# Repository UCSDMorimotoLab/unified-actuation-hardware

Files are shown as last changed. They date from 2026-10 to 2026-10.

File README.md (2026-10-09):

<h1 align="center">A Unified Continuum Robot Actuation Platform - Hardware</h1>

<p align="center">
  Open-source hardware to help researchers get started with high-DOF robots.<br>
  We focus on continuum robots, but the platform is agnostic to robot type!
</p>

<p align="center">
  <a href="https://ucsdmorimotolab.github.io/unified-actuation/"><b>Project website</b></a>
  &nbsp;·&nbsp;
  <a href="https://drive.google.com/file/d/1_eJ_vQgiMd1IlGs77tz4AiUZTHAcJVn4/view"><b>Full actuation assembly video</b></a>
  &nbsp;·&nbsp;
  <a href="https://github.com/UCSDMorimotoLab/unified-actuation-software"><b>Looking for software?</b></a>
</p>

---

## What's in this repo

| | |
|---|---|
| [Assembly guide](AssemblyDoc_6-24-2026.pdf) | Step-by-step mechanical assembly instructions (PDF) |
| [Bill of materials](BOM_6-25-2026.xlsx) | Parts list for the actuation system (Excel) |
| [CAD and print files](CAD_and_print_files/) | SolidWorks assemblies and 3D-print files |

The [full actuation assembly video](https://drive.google.com/file/d/1_eJ_vQgiMd1IlGs77tz4AiUZTHAcJVn4/view) walks through the complete build alongside the assembly guide.

## System overview

<p align="center">
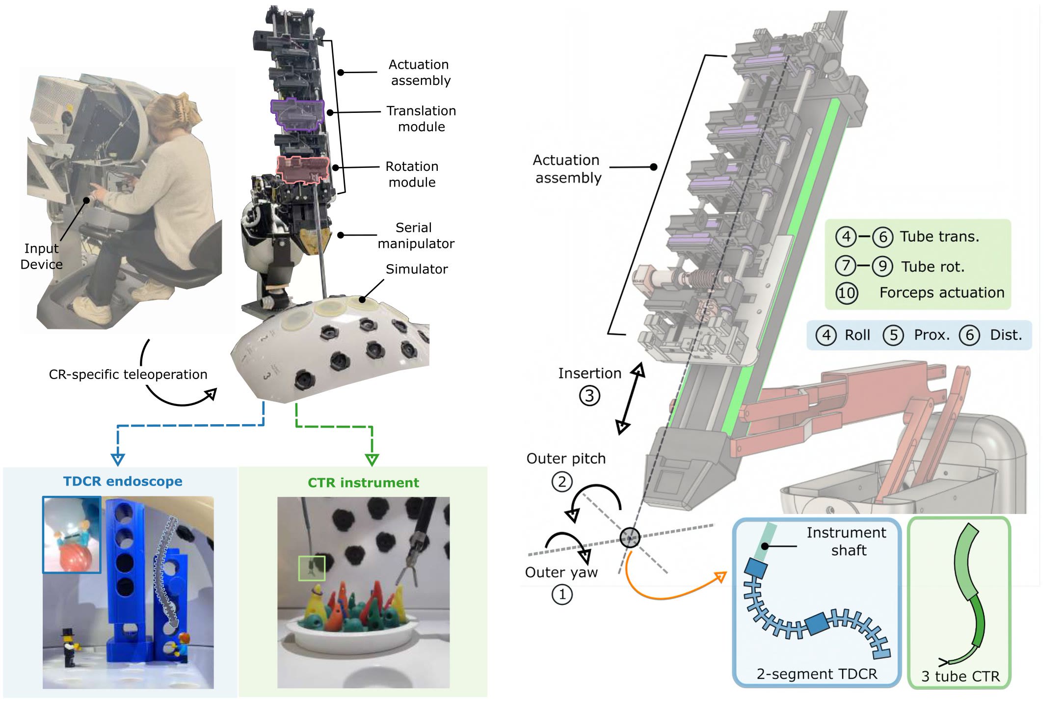
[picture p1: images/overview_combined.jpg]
Left: system overview, an operator at the input device teleoperates the actuation assembly on a serial manipulator over a surgical simulator, driving a TDCR endoscope and a CTR instrument. Right: degrees of freedom, outer yaw, outer pitch and insertion plus actuation-assembly DOFs for a 2-segment T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
  
</p>

## Design overview

<p align="center">
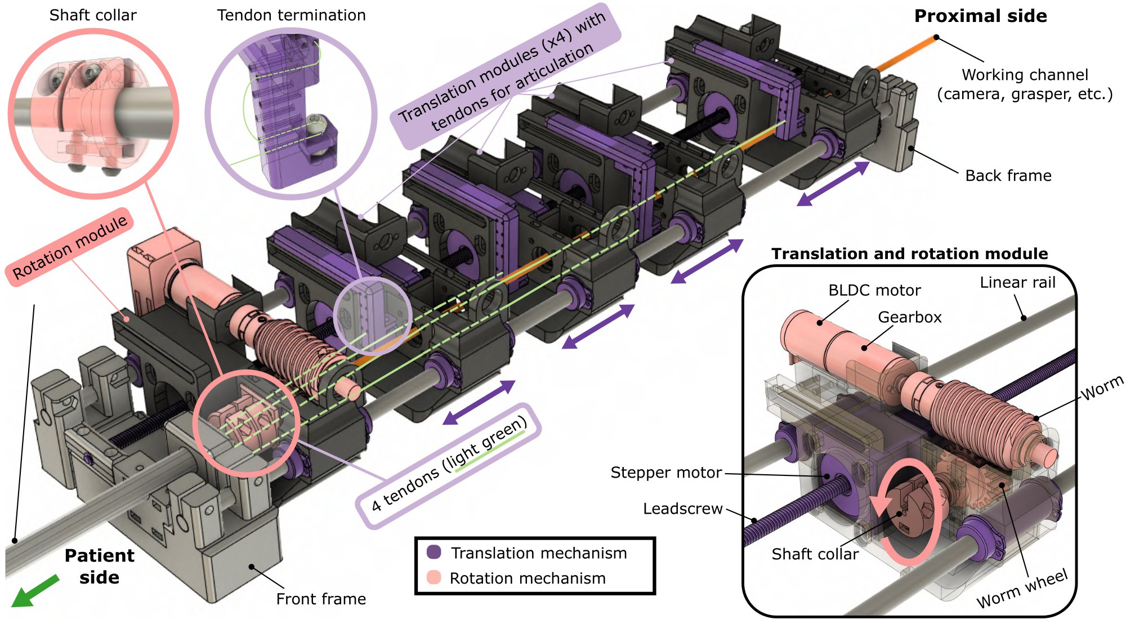
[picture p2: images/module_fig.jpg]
Annotated CAD render of the actuation assembly: a rotation module and four translation modules on linear rails, with tendons routed to each module and a central working channel
  
</p>

<p align="center">
  <em>An example actuation assembly for a TDCR. Modules can be reconfigured to match the robot's design and number of DOFs. A central working channel accommodates cameras, forceps, and other tools.</em>
</p>

## License

The CAD files, print files, and documentation in this repository are released under the [MIT License](LICENSE).

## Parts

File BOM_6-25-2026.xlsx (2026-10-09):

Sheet: Actuation Components for TDCR C
NOTE: "Actuation Components" refers exclusively to the backend motorized drive hardware and explicitly exclude continuum robot assemblies.
 | Price of Actuation Components for Tendon-driven CR (TDCR): | $1095.00 | Price of TDCR: | $110.20
 | Part Name | Vendor | Part No. & Link | Quantity | Price Per Unit | Item Total | Notes
Actuation Components for Tendon-driven Continuum Robot (TDCR) Config (Excludes CR) |  |  |  |  |  |  | - 1 roll module - 4 tendon modules
Off-the-shelf Components | Linear Actuator (Stepper Motor) | Nanotec | LA281S10-A-THCA (https://www.nanotec.com/us/en/products/2405-la281s10-a-thca) | 4 | $113.30 | $453.20
 | Brushless Direct Current (BLDC) Motor | Maxon | 283828 (https://www.maxongroup.us/maxon/view/product/283828) | 1 | $190.88 | $190.88 | - Price at time bought, price as of Jan 30th, 2026 is $206.15 per unit when buying 5 or more
 | BLDC Motor Planetary Gearhead | Maxon | 110322 (https://www.maxongroup.us/maxon/view/product/gear/planetary/gp16/110322) | 1 | $63.13 | $63.13 | - Price at time bought, price as of Jan 30th, 2026 is $68.18 per unit when buying 5 or more
 | Worm Wheel Bearing (Hollow Shaft) | McMaster-Carr | 57155K303 (https://www.mcmaster.com/57155K303/) | 1 | $6.67 | $6.67
 | Worm | McMaster-Carr | 57545K634 (https://www.mcmaster.com/57545K634/) | 1 | $15.63 | $15.63
 | Hollow Shaft (Worm Wheel) | McMaster-Carr | 89495K565-89495K568 (https://www.mcmaster.com/89495K565-89495K568/) | 1 | $17.40 | $17.40 | - For length of 4 ft, buy only once for 2 systems
 | Solid Shaft (Worm Shaft) | McMaster-Carr | 4634T32-4634T323 (https://www.mcmaster.com/4634T32-4634T323/) | 1 | $3.04 | $3.04 | - For length of 3 ft, buy only once for 2 systems
 | Motor (3 mm) Shaft Coupling | McMaster-Carr | 59985K1-59985K101 (https://www.mcmaster.com/59985K1-59985K101/) | 1 | $19.62 | $19.62
 | Worm (6 mm) Shaft Coupling | McMaster-Carr | 59985K1-59985K104 (https://www.mcmaster.com/59985K1-59985K104/) | 1 | $19.62 | $19.62
 | Open Housing Bearing (Worm) | McMaster-Carr | 57155K472 (https://www.mcmaster.com/57155K472/) | 1 | $10.00 | $10.00
 | Linear Bearing | Misumi | LMUW6 (https://us.misumi-ec.com/vona2/detail/110300026540/?HissuCode=LMUW6) | 10 | $16.58 | $165.80 | - Price when buying more than 10 or more
 | Retaining/Snap Ring | McMaster-Carr | 9968K52 (https://www.mcmaster.com/9968K52/) | 1 | $10.86 | $10.86 | - Sold in Packs of 50, buy only once for both systems
 | Limit Switch | Iridescent (Amazon) | KW11-3Z-2 (https://www.amazon.com/MXRS-5-5cm-Momentary-Button-Switch/dp/B07MW2RPJY?pid=ujgRott&s=industrial) | 1 | $5.29 | $5.29 | - Sold in Packs of 12, buy only once for both systems
 |  |  |  |  |  | 0
 | Linear Motion Shaft | McMaster-Carr | 6112K42 (https://www.mcmaster.com/6112k42/) | 2 | $12.98 | $25.96 | -
 | Lead Screw | Nanotec | SCREW-AAA-THCA-1000 (https://www.nanotec.com/us/en/products/10762-screw-aaa-thca-1000) | 1 | $87.90 | $87.90 | - For length of 1 m, buy only once for 2 systems
Custom Components | Module Frame | Formlabs (Tough 1500 V2) | Module_Frame_012 | 5
 | Worm Wheel | Formlabs (Tough 1500 V2) | Worm_Wheel_003 | 1
 | BLDC Clamp | Bambu Lab (PLA) | BLDC_Constraint | 1
 | Shaft Coupling Disc | Bambu Lab (PLA) | Shaft_Coupling_Disc | 1
 | Worm-Bearing Spacer | Bambu Lab (PLA) | Worm_Spacer_006 | 1
 | Backlash Panel | Bambu Lab (PLA) | Backlash_Panel_003 | 1
 | Shaft Collar - TDCR | Formlabs (Tough 1500 V2) | TDCR_Shaft_Collar | 1
 | Wire Router | Bambu Lab (PLA) | Wire_Router_002 | 5
 | Front Frame | Bambu Lab (PLA) | Front_Frame_008 | 1
 | Back Frame | Bambu Lab (PLA) | Back_Frame_003 | 1
 | Lead Screw Holder Bottom | Bambu Lab (PLA) | Lead_Screw_Holder_Bottom_003 | 2
 | Lead Screw Holder Top | Bambu Lab (PLA) | Lead_Screw_Holder_Top_003 | 2
 | Tendon L Joint | Formlabs (Tough 1500 V2) | LJoint_Tendon_Top_Termination_008 | 4
 | Roll Module Stationary Spacer | Bambu Lab (PLA) | Roll_Module_Stationary_Spacer | 2
 | Internal Tendon Tube Spacer | Formlabs (Tough 1500 V2) | Internal_Tendon_Tube_Spacer_002 | 1
 | TDCR Shaft Holder | Bambu Lab (PLA) | TDCR_Shaft_Holder | 1
 | TDCR Shaft Clamp | Bambu Lab (PLA) | TDCR_Shaft_Clamp | 1 |  |  | - only required to constrain rotation

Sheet: Actuation Components for CTR Co
NOTE: "Actuation Components" refers exclusively to the backend motorized drive hardware and explicitly exclude continuum robot assemblies.
 | Price of Actuation Components for Concentric Tube Robots (CTR): | $1918.08 | Price of CTR: | $651.47
 | Part Name | Vendor | Part No. & Link | Quantity | Price Per Unit | Item Total | Notes
Actuation Components for Concentric Tube Robot (CTR) Config (Excludes CR) |  |  |  |  |  |  | - 3 CTR modules - Instrument module
Off-the-shelf Components | Linear Actuator (Stepper Motor) | Nanotec | LA281S10-A-THCA (https://www.nanotec.com/us/en/products/2405-la281s10-a-thca) | 3 | $113.30 | $339.90
 | Brushless Direct Current (BLDC) Motor | Maxon | 283828 (https://www.maxongroup.us/maxon/view/product/283828) | 4 | $190.88 | $763.52 | - Price at time bought, price as of Jan 30th, 2026 is $206.15 per unit when buying 5 or more
 | BLDC Motor Planetary Gearhead | Maxon | 110322 (https://www.maxongroup.us/maxon/view/product/gear/planetary/gp16/110322) | 4 | $63.13 | $252.52 | - Price at time bought, price as of Jan 30th, 2026 is $68.18 per unit when buying 5 or more
 | Worm Wheel Bearing (Hollow Shaft) | McMaster-Carr | 57155K303 (https://www.mcmaster.com/57155K303/) | 6 | $6.67 | $40.02
 | Worm | McMaster-Carr | 57545K634 (https://www.mcmaster.com/57545K634/) | 3 | $15.63 | $46.89
 | Hollow Shaft (Worm Wheel) | McMaster-Carr | 89495K565-89495K568 (https://www.mcmaster.com/89495K565-89495K568/) | 1 | $17.40 | $17.40 | - For length of 4 ft, buy only once for 2 systems
 | Solid Shaft (Worm Shaft) | McMaster-Carr | 4634T32-4634T323 (https://www.mcmaster.com/4634T32-4634T323/) | 1 | $3.04 | $3.04 | - For length of 3 ft, buy only once for 2 systems
 | Motor (3 mm) Shaft Coupling | McMaster-Carr | 59985K1-59985K101 (https://www.mcmaster.com/59985K1-59985K101/) | 4 | $19.62 | $78.48
 | Worm (6 mm) Shaft Coupling | McMaster-Carr | 59985K1-59985K104 (https://www.mcmaster.com/59985K1-59985K104/) | 4 | $19.62 | $78.48
 | Open Housing Bearing (Worm) | McMaster-Carr | 57155K472 (https://www.mcmaster.com/57155K472/) | 3 | $10.00 | $30.00
 | Linear Bearing | Misumi | LMUW6 (https://us.misumi-ec.com/vona2/detail/110300026540/?HissuCode=LMUW6) | 6 | $16.58 | $99.48 | - Price when buying more than 10 or more
 | Retaining/Snap Ring | McMaster-Carr | 9968K52 (https://www.mcmaster.com/9968K52/) | 1 | $10.86 | $10.86 | - Sold in Packs of 50, buy only once for both systems
 | Limit Switch | Iridescent (Amazon) | KW11-3Z-2 (https://www.amazon.com/MXRS-5-5cm-Momentary-Button-Switch/dp/B07MW2RPJY?pid=ujgRott&s=industrial) | 1 | $5.29 | $5.29 | - Sold in Packs of 12, buy only once for both systems
 |  |  |  |  |  | 0
 | Linear Motion Shaft | McMaster-Carr | 6112K42 (https://www.mcmaster.com/6112k42/) | 2 | $12.98 | $25.96
 | Lead Screw | Nanotec | SCREW-AAA-THCA-1000 (https://www.nanotec.com/us/en/products/10762-screw-aaa-thca-1000) | 1 | $87.90 | $87.90 | - For length of 1 m, buy only once for 2 systems
 |  |  |  |  |  | 0
 | ACME Lead Screw | McMaster-Carr | 99030A981 (https://www.mcmaster.com/99030A981/) | 1 | $23.34 | $23.34
 | ACME Hex Nut | McMaster-Carr | 94815A007 (https://www.mcmaster.com/94815A007/) | 1 | $3.51 | $3.51
 | Compression Spring (23/64 x 1-3/8 in) | Performance Tool (O'Reilly Auto Parts) | W5200 (https://www.oreillyauto.com/detail/c/performance-tool/performance-tool-200-piece-spring-assortment/pfm0/w5200) | 1 | $11.49 | $11.49 | - 200 part spring assortment but only need 1 unit of 1 specific spring
Custom Components | Module Frame | Formlabs (Tough 1500 V2) | Module_Frame_012 | 3
 | Worm Wheel | Formlabs (Tough 1500 V2) | Worm_Wheel_003 | 3
 | BLDC Clamp | Bambu Lab (PLA) | BLDC_Constraint | 3
 | Coupling Disc | Bambu Lab (PLA) | Shaft_Coupling_Disc | 4
 | Worm Bearing Spacer | Bambu Lab (PLA) | Worm_Spacer_006 | 3
 | Backlash Panel | Bambu Lab (PLA) | Backlash_Panel_003 | 3
 | Shaft Collar - CTR Tube 1 | Formlabs (Tough 1500 V2) | CTR_Shaft_Collar_Tube1 | 1
 | Shaft Collar - CTR Tube 2 | Formlabs (Tough 1500 V2) | CTR_Shaft_Collar_Tube2 | 1
 | Shaft Collar - CTR Tube 3 | Formlabs (Tough 1500 V2) | CTR_Shaft_Collar_Tube2 | 1
 | Wire Router | Bambu Lab (PLA) | Wire_Router_002 | 5
 | Front Frame | Bambu Lab (PLA) | Front_Frame_008 | 1
 | Back Frame | Bambu Lab (PLA) | Back_Frame_003 | 1
 | Lead Screw Holder Bottom | Bambu Lab (PLA) | Lead_Screw_Holder_Bottom_003 | 2
 | Lead Screw Holder Top | Bambu Lab (PLA) | Lead_Screw_Holder_Top_003 | 2
 | CTR Tube Holder | Bambu Lab (PLA) | CTR_Tube_Holder
 | Instrument Module Frame | Bambu Lab (PLA) | Instrument_ModuleM6_Frame_002 | 1
 | Instrument Tendon Constraint Module | Bambu Lab (PLA) | Instrument_Tendon_Termination_Module_004 | 1
 | Instrument Spacer | Bambu Lab (PLA) | Instrument_Spacer

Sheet: Electronic Components
 | Price of Electronic Components for 2 Complete Systems: | $3530.288
 | Part Name | Vendor | Part No. & Link | Quantity | Price Per Unit | Item Total | Notes
Electronic Components |  |  |  |  |  |  | - supports 2 actuation systems, 1 CTR and 1 TDCR
Off-the-shelf Components | Nanotec Motor Controller Boards | Nanotec | CM-CPB3-44-0005-1 (https://www.nanotec.com/us/en/products/10303-cm-cpb3-44-0005-1) | 3 | $933 | $2799
 | 60V, 15A, 300W Power Supply | Multicomp Pro (Newark) | MP710257 US (https://www.newark.com/multicomp-pro/mp710257-us/dc-power-supply-prog-15a-60v-300w/dp/42AH2837) | 1 | $324 | $324
 | TP-Link 5 Port Ethernet Switch | TP-Link (Amazon) | TL-SG105 (https://www.amazon.com/gp/product/B00A128S24/ref=ox_sc_act_title_8?smid=ATVPDKIKX0DER&th=1) | 1 | $17.99 | $17.99
 | 22 Gauge 8 Conductor Electrical Wire | LEDLampsWorld (Amazon) | B0CLZDX27V (https://www.amazon.com/gp/product/B0CLZDX27V/ref=ox_sc_act_title_7?th=1) | 2 | $44.99 | $89.98 | - 100 ft per order
 | 22 Gauge 4 Conductor Electrical Wire | Enerjour (Amazon) | 22-4C-100FT-CA-ZW (https://www.amazon.com/Conductor-Electrical-Stranded-Extension-Automotive/dp/B0CV7WLG29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) | 2 | $33.98 | $33.98 | - 100 ft per order
 | Molex Mini-Fit 8 Circuit | DigiKey | 23-0766500077-ND (https://www.digikey.com/en/products/detail/molex/0766500077/2115941) | 17 | $0.94 | $16.05 | - connectors for BLDC motors to Nanotec boards
 | Molex Mini-Fit 4 Circuit | DigiKey | 23-0766500075-ND (https://www.digikey.com/en/products/detail/molex/0766500075/2115923) | 22 | $0.84 | $18.48 | - connectors for stepper motors to Nanotec boards
 | Molex Mini-Fit 2 Circuit | DigiKey | 23-0766500074-ND (https://www.digikey.com/en/products/detail/molex/0766500074/2115924) | 10 | $0.60 | $6.00 | - connectors for limit switches to Nanotec boards
 | 8 pin jumper Female 2.54 pitch | DigiKey | 1528-4939-ND (https://www.digikey.com/en/products/detail/adafruit-industries-llc/4939/14552336) | 6 | $0.95 | $5.70
 | 2x12 Position Terminal Block Dist. Module | Oono Electronics (Amazon) | ‎D-1410 (https://www.amazon.com/gp/product/B08TBXQ7H6/ref=ox_sc_act_title_3?smid=A2OVMUS055KMW5&th=1) | 1 | $10.99 | $10.99
 | M3 6+6mm F/M Brass Hex Standoff | uxcell (Amazon) | ‎a18091400ux0125 (https://www.amazon.com/gp/product/B07KWVD986/ref=ox_sc_act_title_2?smid=A30WUG2ZDGM0XM&psc=1) | 1 | $9.59 | $9.59
 | Ethernet Cable - Cat 6 | Cable Matters (Amazon) | 160001-BLK-1x5 (https://www.amazon.com/Cable-Matters-5-Pack-Snagless-Ethernet/dp/B00C4U030G) | 1 | $9.99 | $9.99 | - 1 ft length
 | 22 AWG wire | SZNNZD (Amazon) | DGHY-GJX-BOX1 (https://www.amazon.com/dp/B09Y9B4PVN?ref=ppx_yo2ov_dt_b_product_details&th=1) | 2 | $14.99 | $29.98 | - Wiring for individual motor connections
 | 16 AWG wire | Haerkn (Amazon) | ‎B0746HRVZP (https://www.amazon.com/Electrical-Gauge-Silicone-Cable-Black/dp/B0746HRVZP) | 1 | $8.88 | $8.88 | - Wiring for power to each board
 | 3 Fan Kit | Darkrock (Amazon) | B0CD7P3S8Q (https://www.amazon.com/DARKROCK-Computer-Performance-Hydraulic-Warranty/dp/B0CD7P3S8Q) | 1 | $8.99 | $8.99
 | Ethernet Female to Male | Gintooyun (Amazon) | ‎738632035182 (https://www.amazon.com/gp/product/B08D3BQZ77/ref=ox_sc_act_title_2?smid=A1L0CC1FACMFXH&th=1) | 1 | $7.99 | $7.99
 | Velcro Straps | (Amazon) | ‎Ct-ru-50-bk-01 (https://www.amazon.com/50PC-Cable-Ties-Reusable-Multi-Purpose/dp/B0G4CBRPDD) | 1 | $15.99 | $15.99
 | Stepper Connectors | DigiKey | 455-1185-ND (https://www.digikey.com/en/products/detail/jst-sales-america-inc/vhr-4n/608626) | 10 | $0.94 | $9.40
 | Stepper Connector Crimps | DigiKey | 455-1319-1-ND (https://www.digikey.com/en/products/detail/jst-sales-america-inc/SVH-41T-P1-1/26213078) | 100 | $0.06 | $5.87 | - Sold in strips of 100
 | Screw Terminal Block | Recoil (Amazon) | B0B6NZ95CD (https://www.amazon.com/Positive-Negative-Terminal-Distribution-Terminals/dp/B0B6NZ95CD) | 1 | $12.50 | $12.50
 | Male to Female Jumper Row Connector | Dupont (Amazon) | B0CCVHQWFX (https://www.amazon.com/Kidisoii-Dupont-Connector-Pre-Crimped-6P-10CM/dp/B0CCVHQWFX?th=1) | 4 | $11.09 | $44.36
 | Controller Connectors - Logic | DigiKey | 455-1902-ND (https://www.digikey.com/en/products/detail/jst-sales-america-inc/XHP-8/923773) | 25 | $0.08 | $2.10
 | Controller Crimps - Logic | DigiKey | 455-1135-100-ND (https://www.digikey.com/en/products/detail/jst-sales-america-inc/SXH-001T-P0-6/26213115) | 100 | $0.03 | $3.14
 | Controller Connectors - Sensors | DigiKey | 455-2141-ND (https://www.digikey.com/en/products/detail/jst-sales-america-inc/PADP-12V-1-S/1300222) | 25 | $0.21 | $5.14
 | Controller Crimps - Sensors | DigiKey | 455-2147-100-ND (https://www.digikey.com/en/products/detail/jst-sales-america-inc/SPH-001T-P0-5L/27687540) | 100 | $0.04 | $3.94 | - Sold in strips of 100
 | Internal Molex Connectors for Steppers | DigiKey | WM19013-ND (https://www.digikey.com/en/products/detail/molex/0510650600/403570) | 10 | $0.09 | $0.93 | - For extra direct stepper motor wiring
 | Blue Pre-Crimped Wires | DigiKey | 0502128000-12-L4-ND (https://www.digikey.com/en/products/detail/molex/0502128000-12-L4/10131006) | 10 | $0.74 | $7.37 | - For extra direct stepper motor wiring
 | Green Pre-Crimped Wires | DigiKey | 0502128000-12-G4-ND (https://www.digikey.com/en/products/detail/molex/0502128000-12-G4/10131008) | 10 | $0.74 | $7.37 | - For extra direct stepper motor wiring
 | Black Pre-Crimped Wires | DigiKey | 0502128000-12-B4-D-ND (https://www.digikey.com/en/products/detail/molex/0502128000-12-B4-D/10131095) | 10 | $0.72 | $7.22 | - For extra direct stepper motor wiring
 | Red Pre-Crimped Wires | DigiKey | 0502128000-12-R4-D-ND (https://www.digikey.com/en/products/detail/molex/0502128000-12-R4-D/10131100) | 10 | $0.74 | $7.37 | - For extra direct stepper motor wiring
Custom Components | Electronics Housing Back Plate |  | ElectronicsHousing_Back_Plate | 1
 | Electronics Housing Bottom Plate |  | ElectronicsHousing_Bottom_Plate | 1
 | Electronics Housing Front Plate |  | ElectronicsHousing_Front_Plate | 1
 | Electronics Housing Side Plate |  | ElectronicsHousing_Side_Plate | 2
 | Electronics Input/Output Shield |  | ElectronicsHousing_IO_Shield_003 | 1
 | L Bracket |  | ElectronicsHousing_LBracket | 8

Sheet: da Vinci Research Kit (dVRK) At
 | Price of dVRK Attachment Components | $38.18
 | Part Name | Vendor | Part No. & Link | Quantity | Price Per Unit | Item Total | Notes
da Vinci Research Kit (dVRK) Attachment Components |  |  |  |  |  |  | - 1 custom sterile adapter - 1 constant-force spring subassembly - (if CTR) 1 modified subassembly trocar
Off-the-shelf Components | Constant Force Spring (CFS) | McMaster-Carr | 9293K114 (https://www.mcmaster.com/9293K114/) | 1 | $7.70 | $7.70
 | 1/4 in Aluminum Sheet (6" x 6") | ZOFORTY (Amazon) | B0B4DV12NK (https://www.amazon.com/Aluminum-Sheet-Finely-Polished-Deburred/dp/B0B4DV12NK?sp_csd=d2lkZ2V0TmFtZT1zcF9hdGY) | 1 | $18.99 | $18.99
 | Compression Spring (7/32" x 11/16") | Performance Tool (O'Reilly Auto Parts) | W5200 (https://www.oreillyauto.com/detail/c/performance-tool/performance-tool-200-piece-spring-assortment/pfm0/w5200) | 1 | $11.49 | $11.49 | - 200 part spring assortment but only need 2 units of 1 specific spring
Custom Components | Spring to PSM Attachment (Cantilever Support) | Bambu Lab (PLA) | Spring_PSM_Attachment | 1 |  | 0
 | Back Frame Loop Attachment | Bambu Lab (PLA) | Back_Frame_Loop | 1 |  | 0
 | CFS Spool | Bambu Lab (PLA) | SpringSpool_PSM_Insert | 1 |  | 0
 | CFS Spool End Cap | Bambu Lab (PLA) | SpringSpool_EndCap |  |  | 0
 | Front Frame CFS Attachment | Bambu Lab (PLA) | Spring_FrontFrame_Attachment | 1 |  | 0
 | Custom Aluminum Sterile Adapter | CO2 Laser Cutter | dVRK_Attachment_MetalBoard | 1 |  | 0
 | Sterile Adapter Clamp Handle | Bambu Lab (PLA) | Moving_Jaw_dVRKclamp | 1 |  | 0
 | Sterile Adapter Base | Bambu Lab (PLA) | Fixed_Jaw_dVRKclamp | 1 |  | 0
 |  |  |  |  |  | 0
 | Modified Trocar Base | Bambu Lab (PLA) | Trocar_Extension_Base_006 | 1 |  | 0
 | Modified Trocar Cover | Bambu Lab (PLA) | Trocar_TopCover | 1 |  | 0
 | Trocar Clamp | Bambu Lab (PLA) | Trocar_EndClamp | 1 |  | 0

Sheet: General Components
 | Price of General Components | $406.76
 | Part Name | Vendor | Part No. & Link | Quantity | Price Per Unit | Item Total | Notes
General Components |  |  |  |  |  |  | - supports 2 actuation systems, 1 CTR and 1 TDCR
Consumables | Assorted M2 Bolts (Socket Head) | Kindroufly (Amazon) | B0B88RFGY9 (https://www.amazon.com/Kindroufly-Washers-Assortment-Stainless-Machine/dp/B0B88RFGY9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) | 2 | $9.98 | $19.96
 | Assorted M2.5 Bolts (Button Head) | Kindroufly (Amazon) | B0B88KWDJ1 (https://www.amazon.com/Kindroufly-Washers-Assortment-Stainless-Machine/dp/B0B88KWDJ1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) | 1 | $9.99 | $9.99
 | Assorted M4 Bolts (Button Head) | Kindroufly (Amazon) | B0B88JB1MK (https://www.amazon.com/Kindroufly-Washers-Assortment-Stainless-Machine/dp/B0B88JB1MK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) | 1 | $9.98 | $9.98
 | Heat-set Inserts |  |  |  |  | 0
 |  |  |  |  |  | 0
 | Tough 1500 V2 Cartridge | Formlabs | RS-C2-TO15-02 (https://formlabs.com/store/materials/tough-1500-resin/) | 2 | $149 | $298
 | Polylactic Acid (PLA) Basic | Bambu Lab | Link (https://us.store.bambulab.com/products/pla-basic-filament) | 2 | $19.99 | $39.98
Reusable Tools | Retaining/Snap Ring Pliers | Irwin (MSC Industrial Direct) | 74039595 (https://www.mscdirect.com/product/details/74039595) | 1 | $18.67 | $18.67
 | 1.5 mm Hex Key | McMaster-Carr | 7289A11 (https://www.mcmaster.com/7289A11/) | 1 | $0.25 | $0.25
 | Hex Fold-up Keys | Bondhus (Amazon) | 12591 (https://www.amazon.com/Bondhus-12591-GorillaGrip-Fold-up-16-Inch/dp/B0006O4AFQ) | 1 | $9.93 | $9.93

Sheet: Continuum Robotic Components
 | Price of TDCR Driven Components | $110.20 | Price of CTR Driven Components: | $651.47
 | Part Name | Vendor | Part No. & Link | Quantity | Price Per Unit | Item Total | Notes
Continuum Robotic Components
TDCR Components (Example Shown in Paper Provided) | Plastic Tube Shaft | McMaster-Carr | https://www.mcmaster.com/8585K821/ | 1 | $4.20 | $4.20
 | 2.8 mm Camera | DoTheCamera | AMC0115USB-D2.8-1.1 (https://dothecamera.com/product/2-8mm-endoscope-module-usb/) | 1 | $106.00 | $106.00
 | Fishing String Wire |  |  |  |  | $0.00
 |  |  |  |  |  | $0.00
 |  |  |  |  |  | $0.00
 | Tendon-driven Continuum Robot (TDCR) | Formlabs (Tough 1500 V2) | CR_dVRK-wrist_321_SLA |  |  | $0.00
 | Tip-mount for Camera | Formlabs (Tough 1500 V2) | CAD Part Name Hyperlinked to Github |  |  | $0.00
CTR Components (Example Shown in Paper Provided) | Xu NiTi Tube 1 | Meko Metalworks | N/A | 1 | $36.10 | $36.10 | - Based on price quoted from Meko metalworks on January 7, 2025
 | Xu NiTi Tube 2 | Meko Metalworks | N/A | 1 | $36.10 | $36.10 | - Based on price quoted from Meko metalworks on January 7, 2025
 | Xu NiTi Tube 3 | Meko Metalworks | N/A | 1 | $36.10 | $36.10 | - Based on price quoted from Meko metalworks on January 7, 2025
 | Heat Treatment for NiTi Tubes | Meko Metalworks | N/A | 1 | $480.00 | $480.00 | - Based on price quoted from Meko metalworks on January 7, 2025
 | Stainless Steel Tube Extension for Tube 1 | McMaster-Carr | 8987K39-8987K517 (https://www.mcmaster.com/8987K39-8987K517/) | 1 | $20.14 | $20.14 | - For length of 3 ft
 | Stainless Steel Tube Extension for Tube 2 | McMaster-Carr | 5560K29-5560K321 (https://www.mcmaster.com/5560K29-5560K321/) | 1 | $24.40 | $24.40 | - For length of 3 ft
 | Stainless Steel Tube Extension for Tube 3 | McMaster-Carr | 8987K24-8987K512 (https://www.mcmaster.com/8987K24-8987K512/) | 1 | $21.49 | $21.49 | - For length of 3 ft
 | Loctite 820 | Loctite (Amazon) | 620 442-62040 (https://www.amazon.com/Loctite-442-62040-Retaining-Compound-Temperature/dp/B000O05C2W) | 1 | $17.35 | $17.35
 | Pulmonary Biopsy Forceps, Oval Jaws | Olympus (eBay) | Olympus: FB-231D eBay: 186999571718 (https://www.ebay.com/itm/186999571718?itmmeta=01K8SPD7XR985XPF7KG5CMC7GX) | 1 | $15.89 | $15.89 | - This item was modified for the application, the proximal handle was decoupled and the sheath was stripped to expose the internal tendons

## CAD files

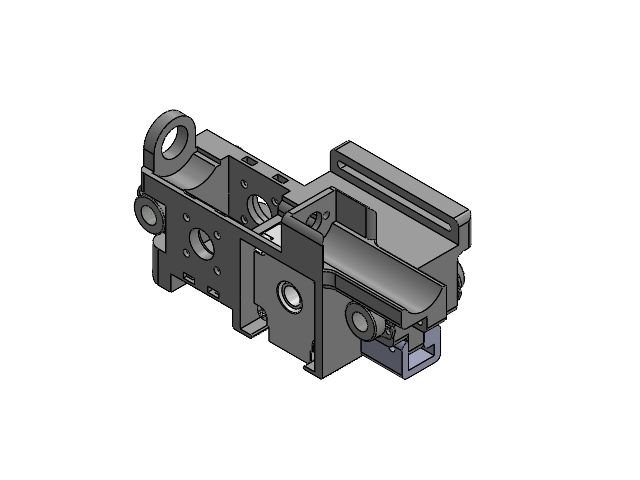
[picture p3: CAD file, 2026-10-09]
CAD_and_print_files/Actuation System Assemblies/Tendon_Module_SubAssem.SLDASM
Module_Frame_012
Stepper_LA281S10-A-THCA
LMUW6 x 2
Wire_Router_002
RetainingRings6mm_9968K52 x 4

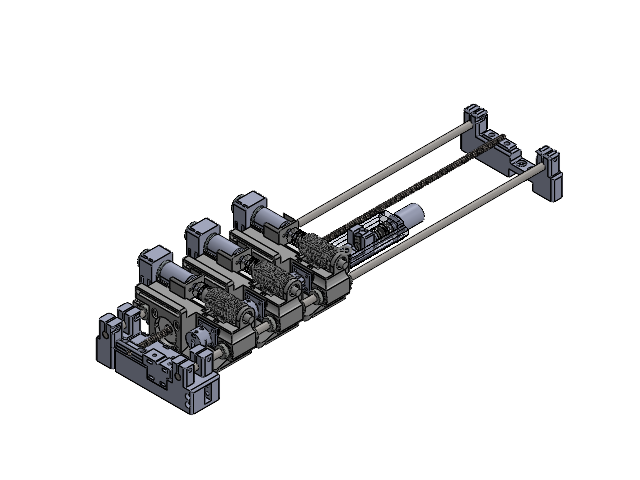
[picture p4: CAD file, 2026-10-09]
CAD_and_print_files/Actuation System Assemblies/CTR_System_Assem006.SLDASM
Back_Frame_003
Front_Frame_008
6112K42_Linear Motion Shaft x 2
Lead_Screw_Holder_Bottom_003 x 2
Lead_Screw_Holder_Top_003
Lead_Screw
Module_Frame_012 x 3
110325_GP16A_0_3NM_5ST_SL.stp x 3
Stepper_LA281S10-A-THCA x 3
MotorShaftCoupling_59985K101 x 4
Shaft_Coupling_Disc x 4
WormShaftCoupling_59985K104 x 4
wormShaft_8920K221 x 3
WormShaftBearing_57155K473 x 3
worm_57545K634 x 3
gearHollowShaft_89955K219 x 3
WormGearShaftBearing_57155K322 x 6
Worm_Wheel_Custom_004 x 3
LMUW6 x 6
BLDCMotor.stp x 3
Wire_Router_002 x 3
Worm_Spacer_006 x 3
Backlash_Panel_003 x 3
BLDC_Constraint x 3
RetainingRings6mm_9968K52 x 12
Instrument_ModuleM6_Frame_002
Instrument_Tendon_Termination_Module_004
98948A111_Acme Hex Nut
95061A601_18-8 Stainless Steel Acme Lead Screw
110324_GP16A_0_25NM_4ST_SL.stp
Instrument_Spacer
CTR_Shaft_Collar_Tube1_002
CTR_Shaft_Collar_Tube2_002
CTR_Shaft_Collar_Tube3_002
CTR_Tube_Holder

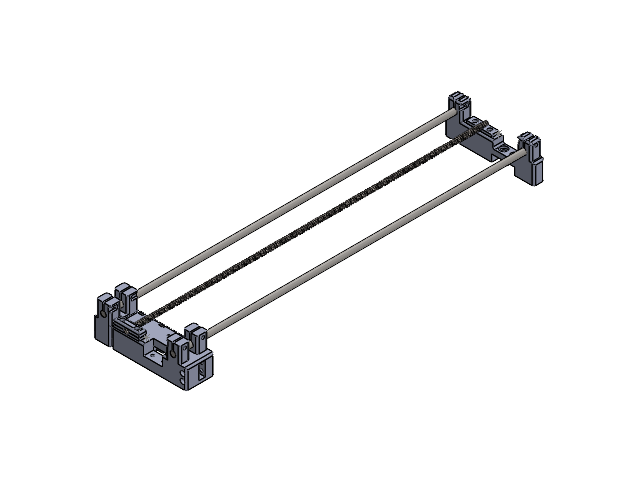
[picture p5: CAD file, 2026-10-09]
CAD_and_print_files/Actuation System Assemblies/Guiderail_SubAssem.SLDASM
Back_Frame_003
Front_Frame_008
6112K42_Linear Motion Shaft x 2
Lead_Screw_Holder_Bottom_003 x 2
Lead_Screw_Holder_Top_003
Lead_Screw

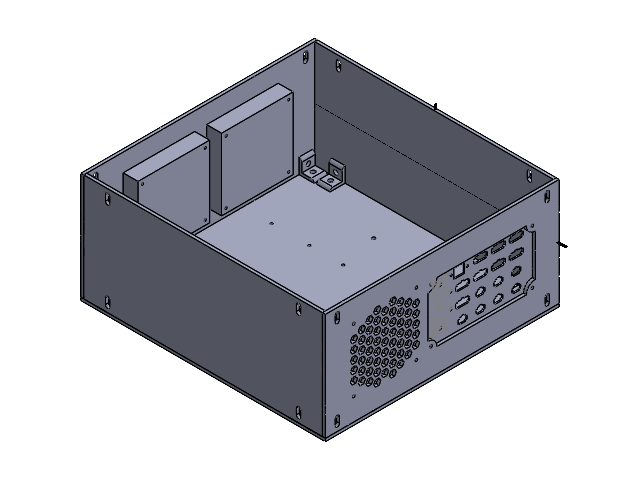
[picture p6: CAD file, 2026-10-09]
CAD_and_print_files/Electronics Housing Box/Electronics_Housing_Box.SLDASM
ElectronicsHousing_Bottom_Plate
ElectronicsHousing_Front_Plate
ElectronicsHousing_Back_Plate
ElectronicsHousing_Side_Plate x 2
ElectronicsHousing_LBracket x 8
Fan x 3
ElectronicsHousing_IO_Shield_003

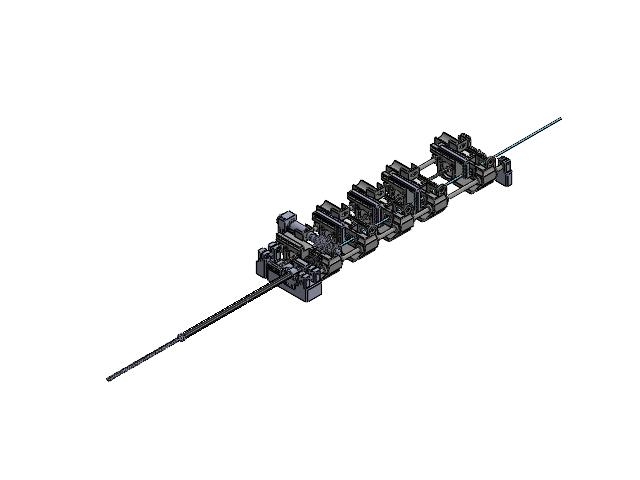
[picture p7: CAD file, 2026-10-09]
CAD_and_print_files/TDCR_in_testingAssem/FinalTDSystemAssem.SLDASM
BackFrameGeneralTestV3
FrontFrameGeneralV3
6112K42_Linear Motion Shaft x 2
LeadScrewHolderBottomV3 x 2
LeadScrewHolderTopV3
LeadScrew
Module_TendonV10 x 5
Stepper_LA281S10-A-THCA x 4
LMUW6 x 10
WireRouterPartV2 x 5
RetainingRings6mm_9968K52 x 20
WorkingChannel
8585K821_Impact-Resistant Polycarbonate Round Tube
InternalTendonSpacerV2 x 2
110325_GP16A_0_3NM_5ST_SL.stp
MotorShaftCoupling_59985K101
FinCouplingDisc_PLA
WormShaftCoupling_59985K104
wormShaft_8920K221
WormShaftBearing_57155K473
worm_57545K634
gearHollowShaft_89955K219
WormGearShaftBearing_57155K322 x 2
wormWheelPrinted_shaftPFV3
BLDCMotor.stp
TendonTubeHolderClamp
BLDCconstraint
OuterRacebacklashpanel_withbackV3
TendonAttachmentSpacer x 2
TDShaftHolder
TDShaftClamp
LJointTendonV8Bottom x 2
LJointTendonV8Top x 2
cDVRK_wrist-321_SLA

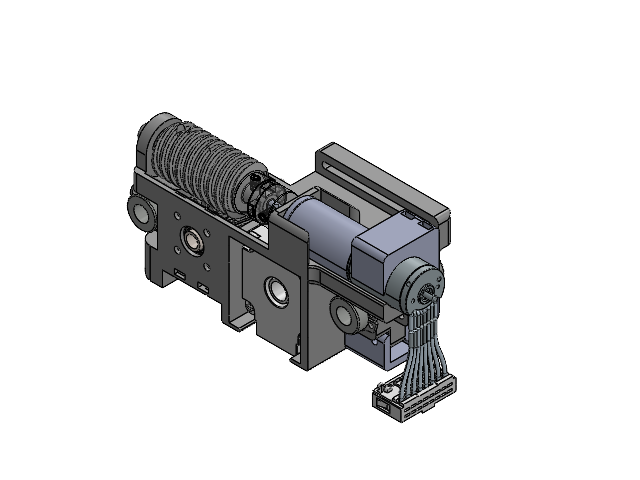
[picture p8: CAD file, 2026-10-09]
CAD_and_print_files/Actuation System Assemblies/CTR_Module_SubAssem.SLDASM
Module_Frame_012
110325_GP16A_0_3NM_5ST_SL.stp
Stepper_LA281S10-A-THCA
MotorShaftCoupling_59985K101
Shaft_Coupling_Disc
WormShaftCoupling_59985K104
wormShaft_8920K221
WormShaftBearing_57155K473
worm_57545K634
gearHollowShaft_89955K219
WormGearShaftBearing_57155K322 x 2
Worm_Wheel_Custom_004
LMUW6 x 2
BLDCMotor.stp
Wire_Router_002
Worm_Spacer_006
Backlash_Panel_003
BLDC_Constraint
RetainingRings6mm_9968K52 x 4

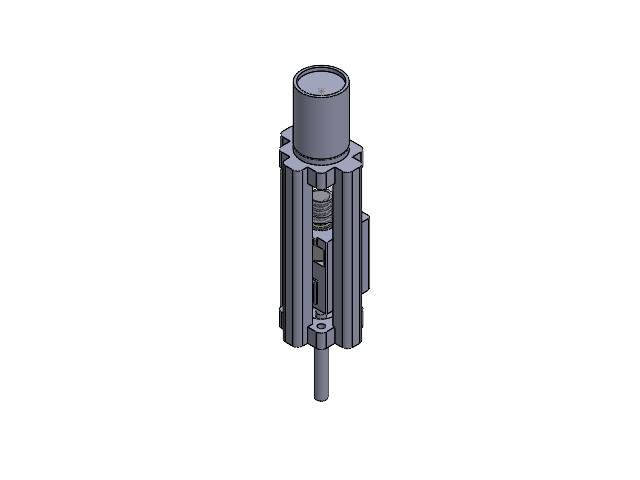
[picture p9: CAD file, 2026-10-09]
CAD_and_print_files/CTR_on_PSM/Instrument Assembly.SLDASM
InstrumentModuleMount
InstrumentWireConstraint_new
98948A111_Acme Hex Nut
95061A601_18-8 Stainless Steel Acme Lead Screw
Shaft Coupler model
110324_GP16A_0_25NM_4ST_SL.stp

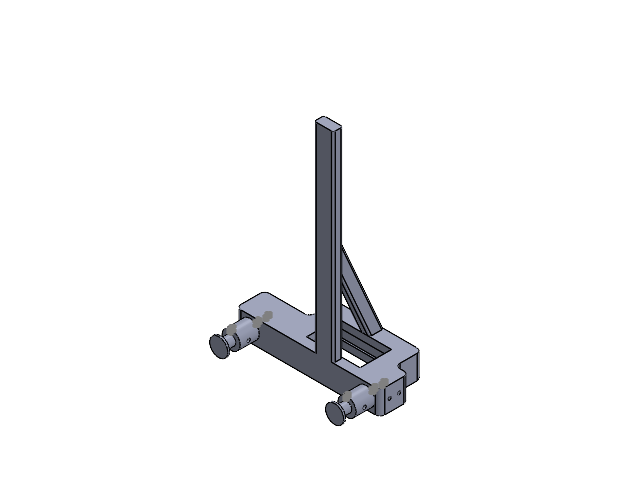
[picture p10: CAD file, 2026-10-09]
CAD_and_print_files/CTR_on_PSM/ConstSpringAttachmentAssem.SLDASM
ConstantForceAttachment
ConstantForceSpool x 2
SpoolEndCap x 2

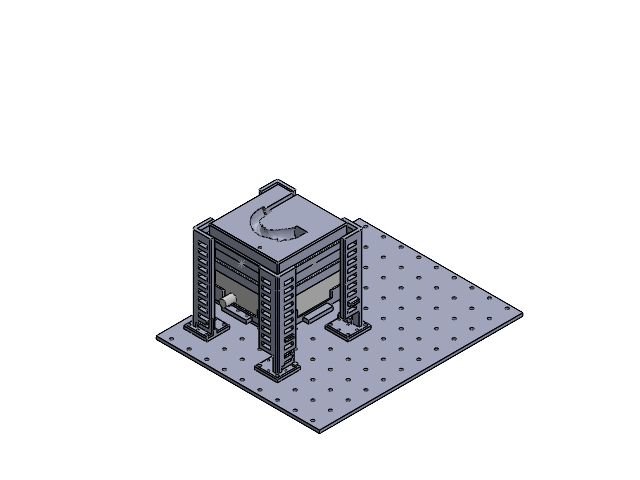
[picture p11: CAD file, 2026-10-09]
CAD_and_print_files/Actuation System Assemblies/Characterization_Testing_Assem.SLDASM
TestingSetup_AcrylicBoard
EM_generator_holder001
MockEM_generator
EMgenerator_Holder_002 x 4
EMgeneratorHolder_SlotPiece x 2
SW_model_D13_neg-003
EM_generator_height_adapter-002
Holder_Pegs

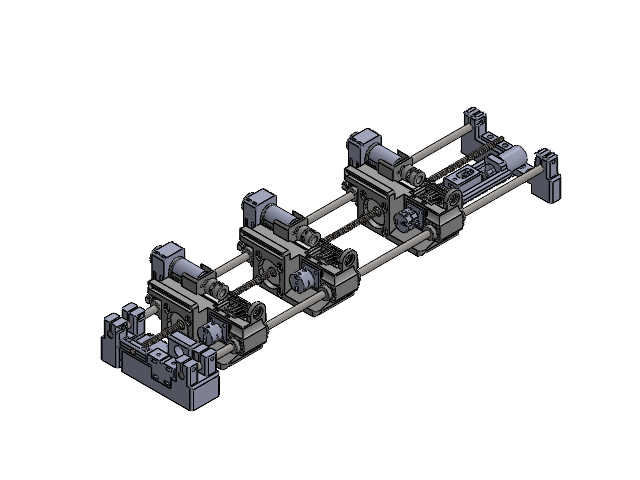
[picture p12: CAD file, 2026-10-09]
CAD_and_print_files/CTR_on_PSM/Final_FullSystem_Assem.SLDASM
BackFrameGeneralTestV3
FrontFrameGeneralV3
6112K42_Linear Motion Shaft x 2
LeadScrewHolderBottomV3 x 2
LeadScrewHolderTopV3
LeadScrew
Module_TendonV10 x 3
110325_GP16A_0_3NM_5ST_SL.stp x 3
Stepper_LA281S10-A-THCA x 3
MotorShaftCoupling_59985K101 x 3
FinCouplingDisc_PLA x 3
WormShaftCoupling_59985K104 x 3
wormShaft_8920K221 x 3
WormShaftBearing_57155K473 x 3
worm_57545K634 x 3
gearHollowShaft_89955K219 x 3
WormGearShaftBearing_57155K322 x 6
wormWheelPrinted_shaftPFV3 x 3
LMUW6 x 6
BLDCMotor.stp x 3
WireRouterPartV2 x 3
WormSpacerV6 x 3
OuterRacebacklashpanel_withbackV3 x 3
BLDCconstraint x 3
RetainingRings6mm_9968K52 x 12
InstrumentModuleMount
InstrumentWireConstraint_new
98948A111_Acme Hex Nut
95061A601_18-8 Stainless Steel Acme Lead Screw
Shaft Coupler model
110324_GP16A_0_25NM_4ST_SL.stp
THC_Tube1ActualV2
THC_Tube2ActualV2
THC_Tube3Actual
CTRTubeHolder

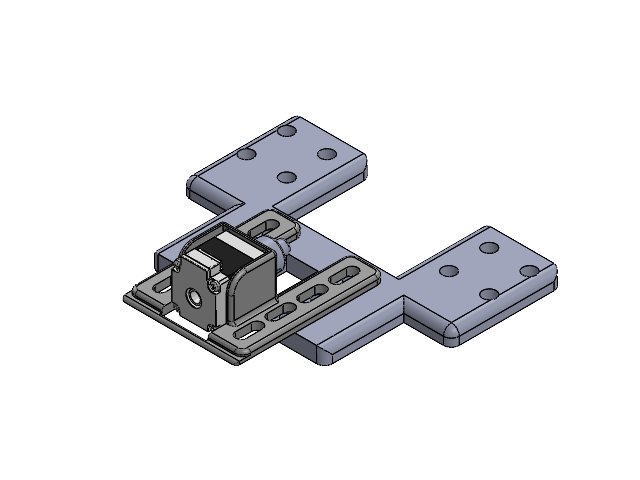
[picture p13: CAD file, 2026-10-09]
CAD_and_print_files/TDCR_in_testingAssem/StepperCharacterizationTestAssem.SLDASM
BLDCMountExtension
Stepper_MountV2
Stepper_LA281S10-A-THCA
MotorLeadScrewCoupleV2-largerOD-Stepper (1)

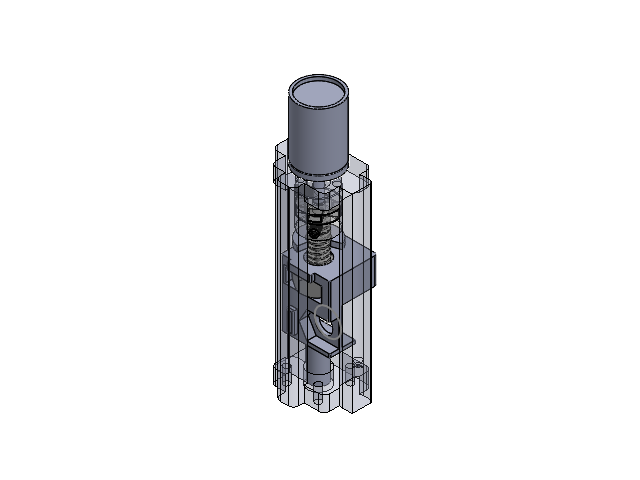
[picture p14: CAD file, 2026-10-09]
CAD_and_print_files/Actuation System Assemblies/Instrument_Module_SubAssem.SLDASM
Instrument_ModuleM6_Frame_002
Instrument_Tendon_Termination_Module_004
98948A111_Acme Hex Nut
95061A601_18-8 Stainless Steel Acme Lead Screw
110324_GP16A_0_25NM_4ST_SL.stp
Instrument_Spacer
MotorShaftCoupling_59985K101
WormShaftCoupling_59985K104
Shaft_Coupling_Disc

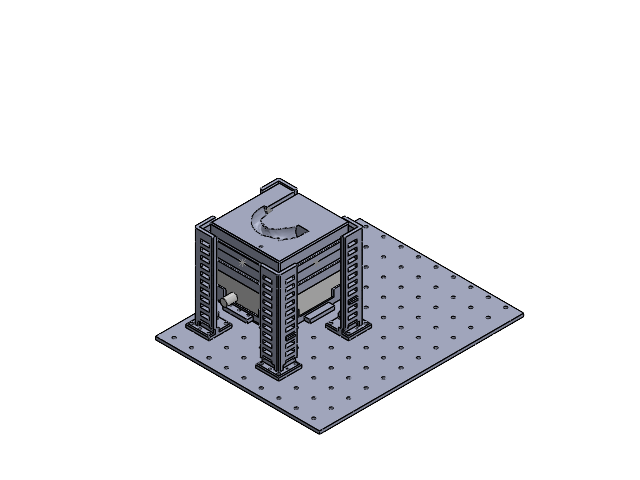
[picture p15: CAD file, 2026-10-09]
CAD_and_print_files/TDCR_in_testingAssem/CharacterizationTestingAssem.SLDASM
AcrylicBoard
EM_generator_holder001
MockEM_generator
AdjustableEMgeneratorHolderV2 x 4
SlotPieceEMgeneratorHolder x 2
SW_model_D13_neg-003
EM_generator_height_adapter-002
HolderPegs

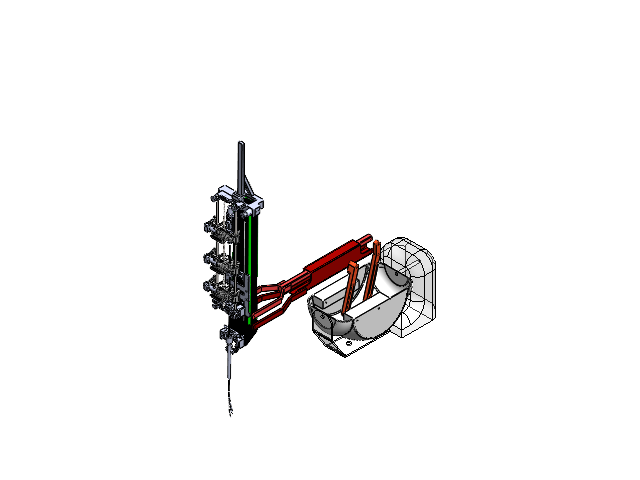
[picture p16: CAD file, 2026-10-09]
CAD_and_print_files/CTR_on_PSM/CTR_on_PSM.SLDASM
L1
L2
LP12
LP11
LP21
LP22
L3
BackFrameGeneralTestV3
FrontFrameGeneralV3
6112K42_Linear Motion Shaft x 2
LeadScrewHolderBottomV3 x 2
LeadScrewHolderTopV3
LeadScrew
Module_TendonV10 x 3
110325_GP16A_0_3NM_5ST_SL.stp x 3
Stepper_LA281S10-A-THCA x 3
MotorShaftCoupling_59985K101 x 3
FinCouplingDisc_PLA x 3
WormShaftCoupling_59985K104 x 3
wormShaft_8920K221 x 3
WormShaftBearing_57155K473 x 3
worm_57545K634 x 3
gearHollowShaft_89955K219 x 3
WormGearShaftBearing_57155K322 x 6
wormWheelPrinted_shaftPFV3 x 3
LMUW6 x 6
BLDCMotor.stp x 3
WireRouterPartV2 x 3
WormSpacerV6 x 3
OuterRacebacklashpanel_withbackV3 x 3
BLDCconstraint x 3
RetainingRings6mm_9968K52 x 12
InstrumentModuleMount
InstrumentWireConstraint_new
98948A111_Acme Hex Nut
95061A601_18-8 Stainless Steel Acme Lead Screw
Shaft Coupler model
110324_GP16A_0_25NM_4ST_SL.stp
THC_Tube1ActualV2
THC_Tube2ActualV2
THC_Tube3Actual
CTRTubeHolder
metaldVRKboardattachment
Fixedjaw_dVRKclamp
Movingjaw_dVRKclamp
BackFrameLoop
ConstantForceAttachment
ConstantForceSpool x 2
SpoolEndCap x 2
TrocarExtensionV4
TrocarInsert
Tube3Xu2025_extended
Tube2Xu2025_extended
Tube1Xu2025_extended

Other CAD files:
CAD_and_print_files/Actuation System Assemblies/dVRK_Clamp_SubAssem.SLDASM
CAD_and_print_files/TDCR_in_testingAssem/Final_Bearing_SubAssem.SLDASM
CAD_and_print_files/CTR_on_PSM/dVRKclampAssem.SLDASM
CAD_and_print_files/TDCR_in_testingAssem/TDSystemSlider.SLDASM
CAD_and_print_files/Actuation System Assemblies/110324_GP16A_0_25NM_4ST_SL.stp
CAD_and_print_files/Actuation System Assemblies/110325_GP16A_0_3NM_5ST_SL.stp
CAD_and_print_files/Actuation System Assemblies/6112K42_Linear Motion Shaft.SLDPRT
CAD_and_print_files/Actuation System Assemblies/8585K821_Impact-Resistant Polycarbonate Round Tube.SLDPRT
CAD_and_print_files/Actuation System Assemblies/9293K114_Constant-Force Strip Spring.SLDPRT
CAD_and_print_files/Actuation System Assemblies/95061A601_18-8 Stainless Steel Acme Lead Screw.SLDPRT
CAD_and_print_files/Actuation System Assemblies/98948A111_Acme Hex Nut.SLDPRT
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

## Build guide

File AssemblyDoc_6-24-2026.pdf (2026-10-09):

### Module Assembly Instructions:

Modular Multi-Continuum Robot Platform for the da Vinci Research Kit (dVRK)

Mechanical System

Tendon-driven CR (TDCR Actuation System Assembly:
(excluding CR)

Concentric Tube Robot Actuation System Assembly:
(excluding CR)

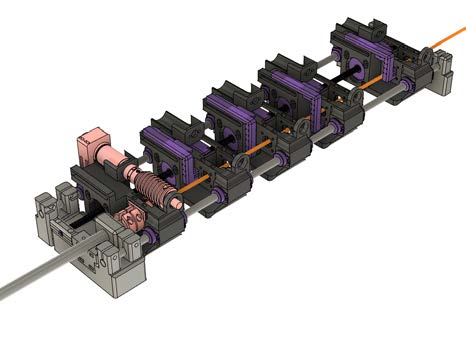
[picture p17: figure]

- 1 roll module
- For roll module assembly do only the following:
■ Worm Assembly
(Bottom, Internal
Section)
- 3 full modules
- For roll module assembly do only the following:
■ Worm Assembly
(Bottom, Internal
Section)

■ Worm Coupling
Assembly (Top Section)
- 4 tendon modules
- For tendon module assembly do only the following:
■ Linear Bearings for
Motion Shafts
■ Stepper Motor
■ Limit Switch
■ Wire Router

■ Worm Coupling
Assembly (Top Section)
■ Linear Bearings for
Motion Shafts
■ Stepper Motor
■ Limit Switch
■ Wire Router

1x roll module
- Rotation subassembly
- Missing translation assembly

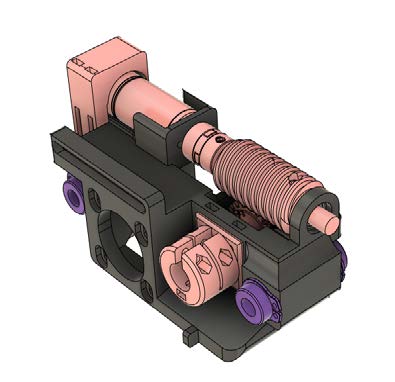
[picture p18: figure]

1x tendon module
- Missing rotation subassembly
- Translation assembly

3x full modules
- Rotation subassembly
- Translation subassembly

For manufacturing of all custom components, outside of the tools mentioned, you require access to:
- 3D Printer FDM - i.e. Bambu Lab X1 Carbon
- 3D Printer SLA - i.e. Formlabs Form 4 printer
- Metal Laser Cutter - Fablight
- Hand saw OR band saw

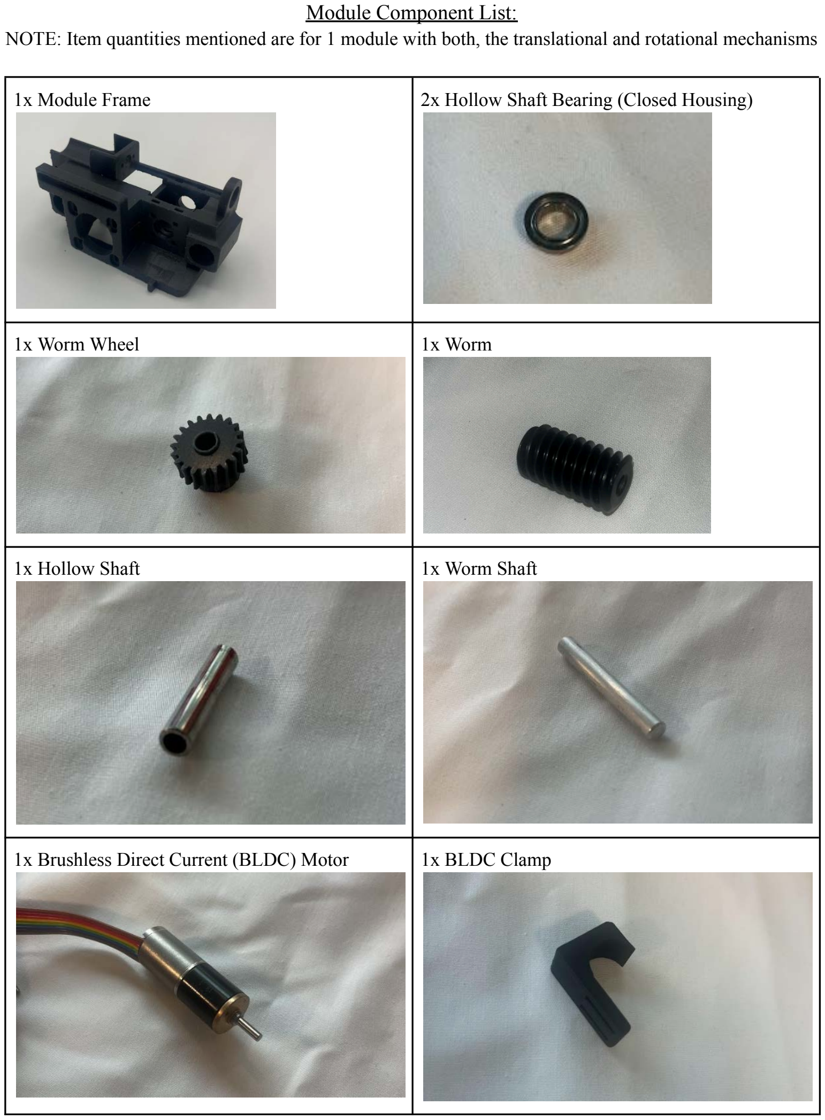
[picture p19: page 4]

Module Component List:
NOTE: Item quantities mentioned are for 1 module with both, the translational and rotational mechanisms
1x Module Frame | 2x Hollow Shaft Bearing (Closed Housing)
1x Worm Wheel | 1x Worm
1x Hollow Shaft | 1x Worm Shaft
1x Brushless Direct Current (BLDC) Motor | 1x BLDC Clamp

1x Motor Shaft Coupling | 1x Coupling Disc
1x Worm Shaft Coupling | 1x Worm Shaft Bearing (Open Housing)
1x Worm-Bearing Spacer | 1x Backlash Panel
2x Linear Bearing | 4x Snap Ring

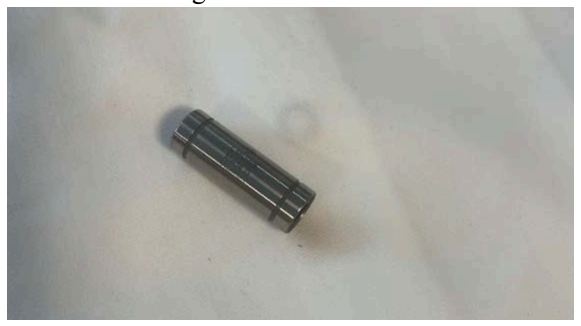
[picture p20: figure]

1x Stepper Motor | 1x Wire Router

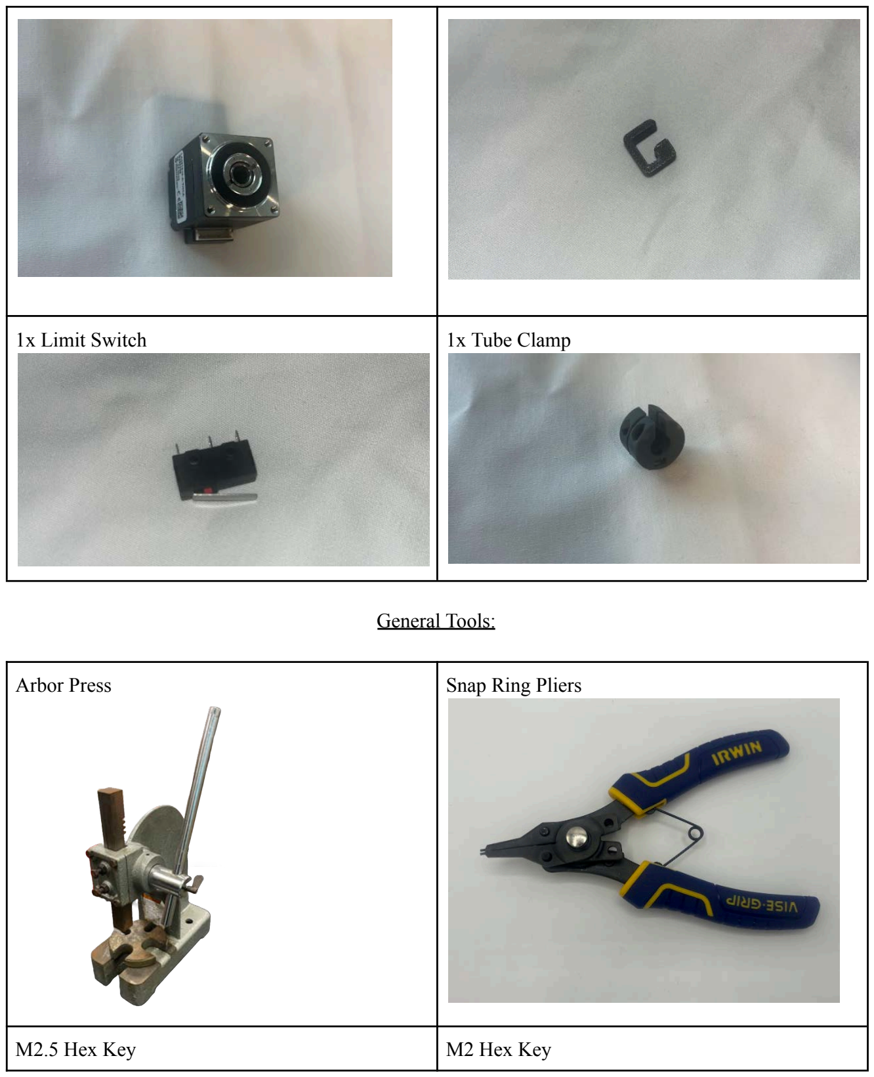
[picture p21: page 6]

1x Limit Switch | 1x Tube Clamp

General Tools:

Arbor Press | Snap Ring Pliers
M2.5 Hex Key | M2 Hex Key

Bearing Assembly Box Tool | Flat-end Tweezers

### Manufacturing Instructions

Module Frame (resin printing):
- Components Required
- Form 4
- Tough Resin 1500 V2

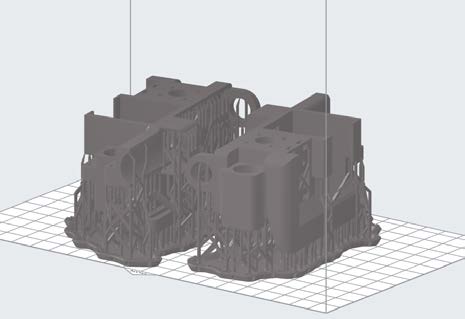
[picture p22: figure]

Print Options in Slicer:
- Print in the orientation such that no supports in the linear bearing (make the front face the bottom)
- Change the touchpoint size of supports to 0.30 mm for better surface finish
- Preform file in Github repo available for download

Post Processing: ● Wash in IPA wash station for 15 minutes ● Shake dry and drain IPA as much as possible ● Cure in cure station for 60 minutes at 70 degrees Celsius | Standard Formlabs cleaning procedure

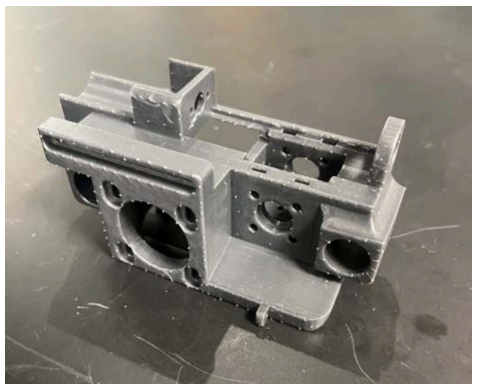
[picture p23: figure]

Support Clearing: ● Use wire cutters to cut off supports and break off the rest by hand, ensure that the back face of the resin module where the slot for the worm wheel lies and edges of the linear bearing holders are flat, removing support remnants through sanding/scraping

Shaft Cuts to Length:
- Components Required
- Band saw / hand saw
- Hollow shaft
- Worm shaft
- Lead screw

Cut hollow shaft using a band saw or hand saw to 36 mm (37 mm is also okay)

Hollow shaft indicated above

Cut worm shaft using a band saw or hand saw to 47 mm (48 mm is also okay) | Worm shaft indicated above

Use a file and/or a belt sander to remove burrs and fix sections of the shafts bowing in or out

Cutting lead screw: ● To maintain the cleanness of the thread, put the hex nut deep onto the lead screw before cutting ● Cut the lead screw using a band saw or hand saw to 400 mm or to desired length. ● Unscrew hex nut to make the thread of the lead screw undamaged and clean out remnant chips

### Module Assembly Instructions

NOTE: item quantities listed of components required are per module and not representative of how many are required for a complete system

Worm Wheel Assembly (Bottom Internal Section, Worm Wheel):
- Components Required
- 2x hollow shaft bearing
- 1x backlash panel
- 1x worm wheel
- 4x M2 hex nuts
- 4x M2x6 bolts
- Auxiliary Items
- Arbor press
- M2 hex key

Put the hollow shaft bearing in the front wall housing with the flange closer to the front side, ensure it has snapped into place within its housing ● Push as far as possible, an existing flange limits maximum depth to intended position

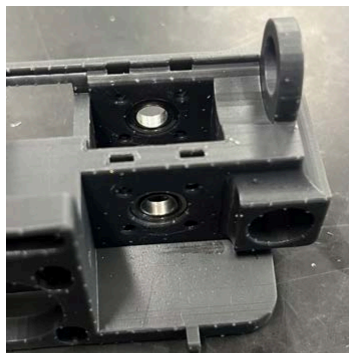
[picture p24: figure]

Fit the second hollow shaft bearing in the back wall into place with a snap, ensure the flange is closer to the front side ● Fit it from the inside hollow section and push towards the back, do not fit it from the outside face inwards ● Push as far as possible, an existing flange limits maximum depth to intended position

Worm wheel
- Put M2 hex nuts into worm wheel
- Place worm wheel inside module with gear teeth closer to the back wall of the module
- Push the worm wheel inside until hole is somewhat concentric with bearings
- Might be a very tight fit but it should work as intended

Exercise caution while using the arbor press here.
- Ensure all sides of the square profile of the arbor press’ ram fit within the module without scraping anything
- Refer to pictures of what not to do:
- In the first image, be careful of hitting the side wall and
compressing or scraping that side
- In the second image, be careful of hitting the sloped surface on the bottom of the module and
scraping material

Correct alignment, what to do:

Be mindful of, what not to do:

Press fit the hollow shaft into the first bearing using the bearing assembly tool
- Place module frame with bearings inside and worm wheel inside with back face down in the arbor press
- Fit the bearing box assembly tool on top of the bearing and put the hollow shaft through it to ensure straight alignment when putting the hollow shaft in
- Once shaft is flush with the top of the bearing box assembly tool, the shaft is successfully press fit into the first bearing, you have successfully put the bearing box assembly tool away

Continue the press fit through, push through the worm wheel and then the bearing at the back as well

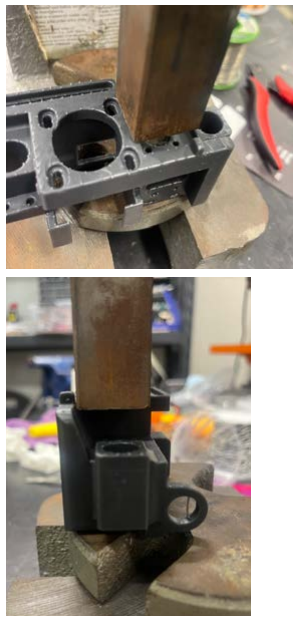
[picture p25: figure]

Final product of press fitting through all components:

- Ensure that the back of module is against a flat face so that you can press fit all the way through to the back
- If you observe flexing of the module, you are applying too much force
- If it feels stuck, release the arbor press force applied and reapply it
- The back wall bearing may require more force to self-align and enter

Secure the hollow shaft bearing in the front wall with a backlash panel
- Begins by putting M2 hex nuts into top slots and pushing hex nuts to full depth and then flipping module frame and putting M2 hex nuts into bottom slots by pushing hex nuts to full depth
- Screw on backlash panel using 2 M2x6 bolts in the diagonal holes for alignment
- Put M2 hex nuts into the remaining two slots and push hex nuts fully in
- Secure bottom section of backlash panel using another 2 M2x6 bolts

For disassembly: use M5 or M6 bolt and push inner hollow shaft out using an arbor press

Worm Gear Assembly (Top Section, Worm)
- Components Required
- 1x BLDC motor
- 1x BLDC clamp
- 1x motor shaft coupling
- 1x coupling disc
- 1x worm shaft coupling
- 1x worm shaft bearing
- 1x worm

- 1x worm wheel
- 2x M2 hex nuts
- 2x M2x8 screws
- 2x M2x12 screws
- Auxiliary Items
- M2 Hex Key
- M2.5 Hex Key

Screw in the BLDC motor with shaft sticking out as shown in image
- Use M2x8 screws

Use the BLDC clamp to hold the back of the BLDC motor in place
- Put 2 M2 hex nuts into the vertical hex nut slots in the BLDC clamp
- Put the BLDC clamp closer to the front side of the module
- Screw in 2 M2x12 bolts through the module, clamp, and hex nut to tighten it at the intended height just touching the BLDC motor

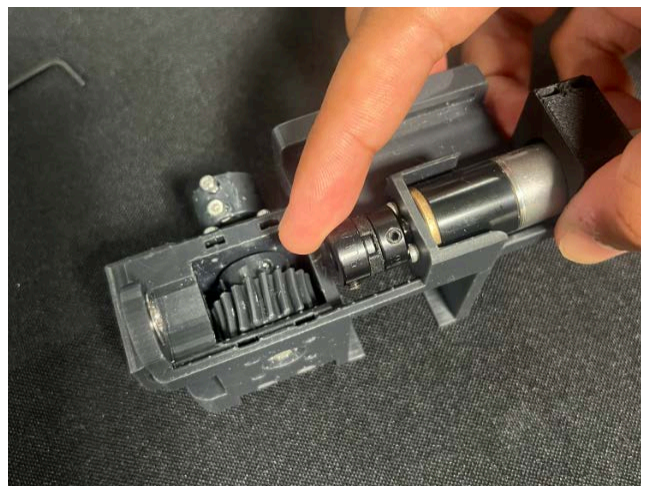
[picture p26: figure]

Put the motor shaft coupling, coupling disc, and worm shaft coupling together, they fit together in a snap fit, orientation relative to one another does not matter as long as it fits
- Motor shaft coupling is the set screw piece with the smaller inner diameter
- Worm shaft coupling is the set screw piece with the bigger inner diameter
- Coupling disc is the thin, 3D-printed piece in between

Attach the motor shaft coupling (motor shaft part) using its built-in set screw onto the flat edge of the motor shaft (D shaft flat edge)
- The motor shaft has a flat face, the set screw should tighten onto this flat face to ensure concentricity

Ensure that the worm shaft coupling (set screw piece on the other side is loosened)

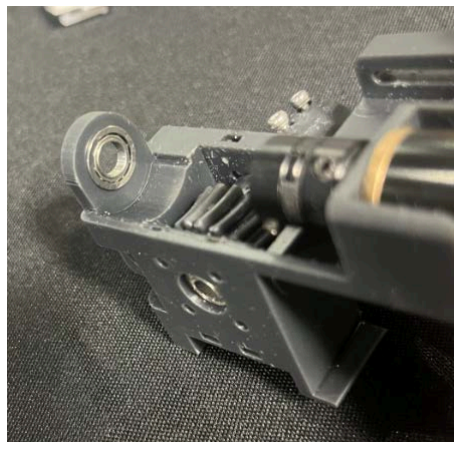
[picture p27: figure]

Put the worm shaft bearing into its housing on the inside face of the module
- The flange is on the inside of the housing

Loosen the motor shaft coupling and push it all the way back towards the motor as shown in the image

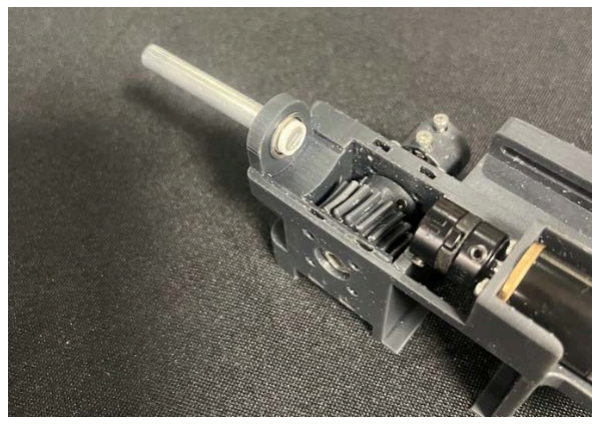
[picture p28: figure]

Hold the 3D-printed worm spacer in place and slide the worm shaft through the bearing and spacer as shown in the image

Put the worm into its place between the spacer and the couplings ● The worm should be placed such that the built-in set screw is on the side that is closer to the worm shaft bearing than the BLDC motor

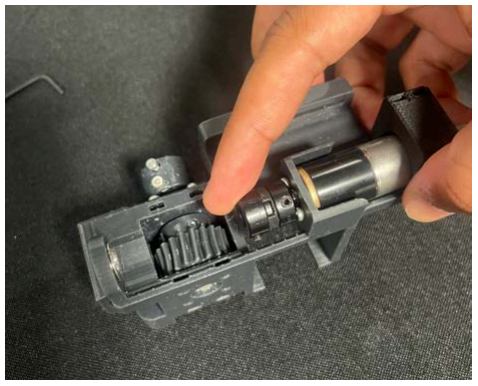
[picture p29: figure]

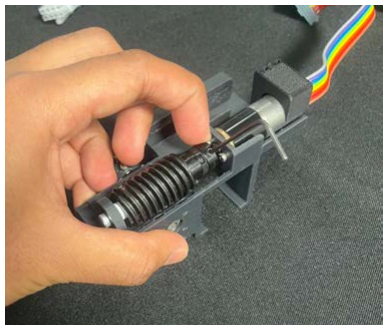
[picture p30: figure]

Push the actual worm shaft into the bearing and all the way through the worm spacer, into the worm, and into the worm shaft coupling Loosen the motor shaft coupling and push the coupling and the rest of the sub assembly in the direction of the bearing such that the whole assembly is in contact, as shown in picture While holding as shown in picture, tighten all set screws

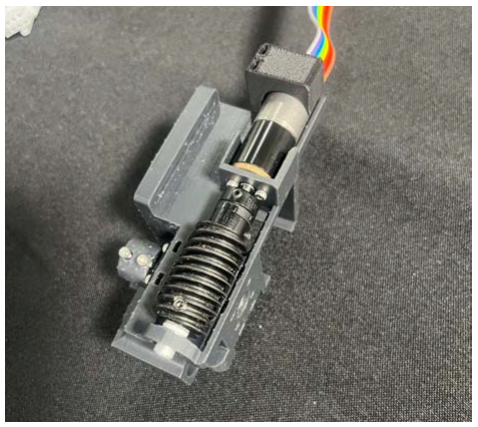
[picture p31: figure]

Re-tighten motor shaft coupling and tighten other set screws (worm shaft couple, worm)

Linear Bearings for Motion Shafts
- Components Required
- 2x linear bearings
- 4x snap rings
- Auxiliary Items
- Snap ring pliers

Exercise caution when handling snap rings with snap ring pliers, be extremely careful of opening the snap rings too far, they have a tendency to permanently (plastically) deform after which they are unusable

Put the snap ring on one side of the linear bearing inside the groove

Push the linear bearings into the circular slots on the sides of the module for it until the inside face of the snap ring hits the module ● Might need arbor press to push linear bearings in if very tight

Put other snap ring on other side of the linear bearing in the groove (should be in opposite orientation as the other snap ring)

Stepper Motor
- Components Required
- 1x stepper motor

- 4x M2.5x8 screws
- Auxiliary Items
- M2.5 hex key

Place stepper motor into the slot in the module for it with electrical connector at the bottom facing forward ● Loosely tighten the M2.5x8 screws into the stepper motor (at least 2 diagonal)

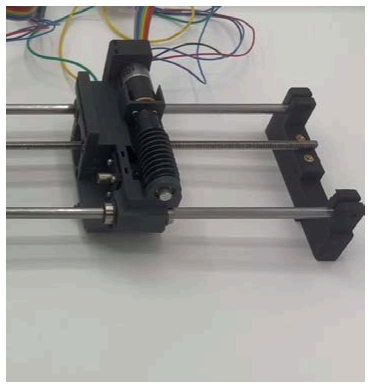
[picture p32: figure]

When system frame is assembled with the lead screw and linear motion shafts, put the module onto the lead screw and linear motion shafts and let the stepper motor naturally settle into its appropriate vertical position ● Ensures alignment of stepper motor on module frame relative to the alignment of lead screw and linear motion shafts

Limit Switch
- Components Required
- 1x limit switch
- 2x M2 hex nuts
- 2x M2x10 screws
- Auxiliary Items
- M2 hex key

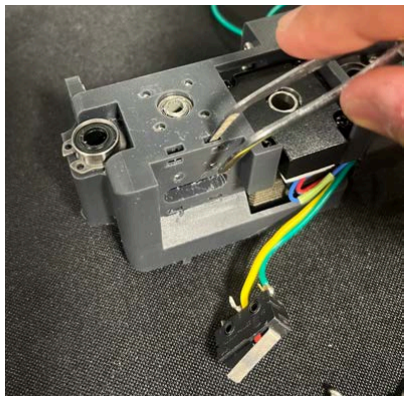
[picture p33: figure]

Put the hex nut into the hex nut slots (M2) ● Ensure they are pushed into full depth ● Refer to image, insert hex nuts into slots where tweezers are entering

Hold the limit switch holes in line with the bolt holes and make sure the pressable tab faces the back of the module ● When looking at the back face of the module, the part that sticks out (pressable tab) more should be on the left side

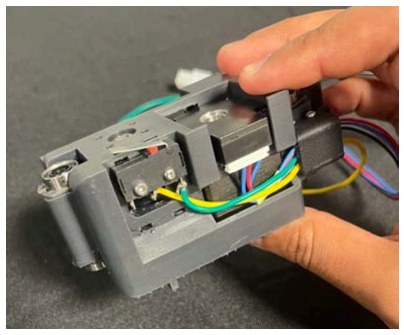
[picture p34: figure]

Use M2x10 bolts to screw limit switch into place

Wire Router
- Components Required
- 1x wire router

- 2x M2 hex nuts
- 2x M2x16 screws
- Auxiliary Items
- M2 hex key

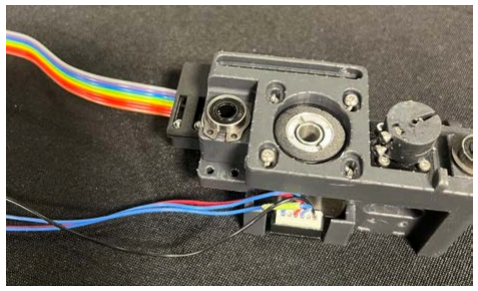
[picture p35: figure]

Keep stepper motor electrical wires and limit switch electrical wires close to the bottom face of the module and route it outwards from the left side (when looking at the front face of the module)

Put hex nuts inside the wire router part ● Be careful and keep vertical orientation of this part during rest of assembly to prevent hex nuts from falling

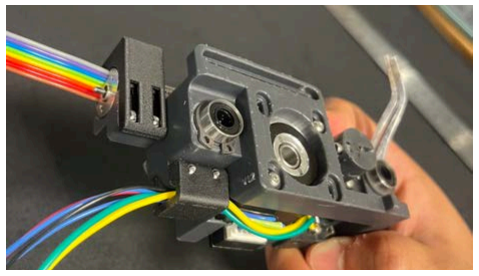
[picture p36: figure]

Slot the wires into the wire router part snugly

Take the wire router part (with wires in place) and put it such that the thicker part is closer to the front face of the module

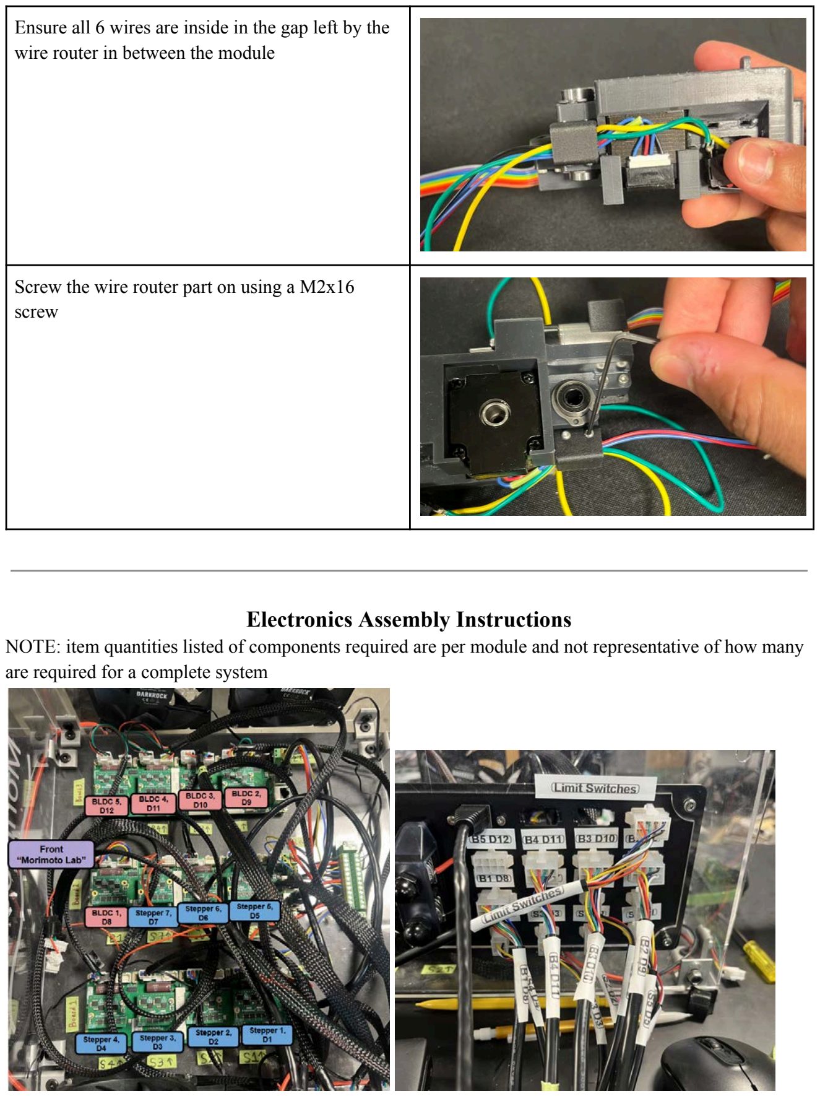
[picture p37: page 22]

Ensure all 6 wires are inside in the gap left by the wire router in between the module

Screw the wire router part on using a M2x16 screw

### Electronics Assembly Instructions

NOTE: item quantities listed of components required are per module and not representative of how many are required for a complete system

Molex Connections:
- Components Required
- 4-pin Molex connectors, male and female
- 8-pin Molex connectors, male and female
- Crimp pins, male and female
- 8 conductor wire
- 4 conductor wire
- Molex crimper or standard crimper

Stepper Motor to Molex Tutorial
- Strip 0.5 cm off of each wire (already done for steppers)
- Get female Molex crimp pin and male Molex connectors
- Crimp each individual wire to the crimp terminal using the appropriate gauge setting
- Ensure outer tab is on top of rubber external and inner tab is on top of wire core
- Slide female crimped wire into male crimped connector
- Black - 1, Green - 2, Red - 3, Blue
- 4 (refer to picture)

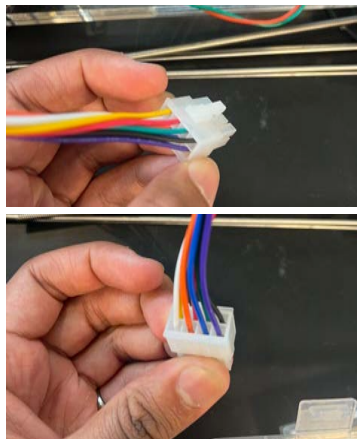
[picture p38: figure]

BLDC Motor to Molex Tutorial
- Insert the pre-provided male crimped wire into the 8 pin connector
- From Amazon order comes
together
- Cut the wires on the other side and strip 0.5 cm of the wire
- Using the female Molex crimp pins, crimp them onto the stripped jumper cables that come off the BLDC motor
- Insert the female Molex crimp pins into the male Molex connector
- Refer to picture for colour order

Molex to Long Wire (extends to dVRK)
- Cut the long 22 gauge cables to 3 m (each motor should have one of these)
- Strip the outer black wire about 4-5 cm
- Strip 0.5 cm off of the internal wires
- Crimp the stripped ends to a male Molex crimp pins
- Slide those male Molex crimp pins into a female Molex connector
- This will connect to the male Molex connectors of the
BLDC/Stepper
- Molex connectors are different for BLDC vs Steppers (8 pin vs 4 pin)
- Repeat this process on the other end with the male Molex equivalent
- Female crimp pins and male Molex connectors which connect to the female Molex connectors on the IO board

Stepper long wire connections

BLDC long wire connections

- For IO board-side connections refer to pictures

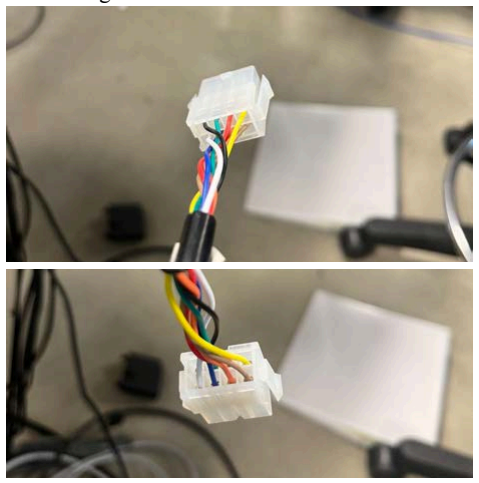
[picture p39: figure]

BLDC long wires, board-side:

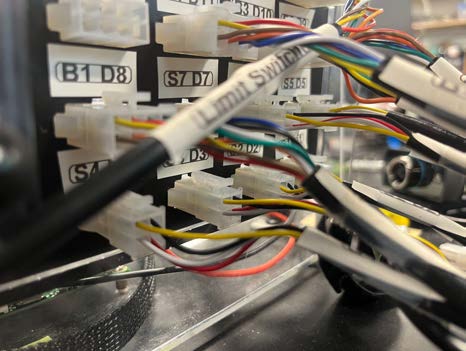
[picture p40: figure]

Stepper long wires, board-side:
